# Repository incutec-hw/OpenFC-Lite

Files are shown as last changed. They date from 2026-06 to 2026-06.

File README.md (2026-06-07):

# OpenFC-Lite

Open-source Betaflight flight controller built on the RP2354B — 6-layer, 30.5×30.5 mm mounting, 3S–6S input, microSD blackbox, analog OSD.

<p>
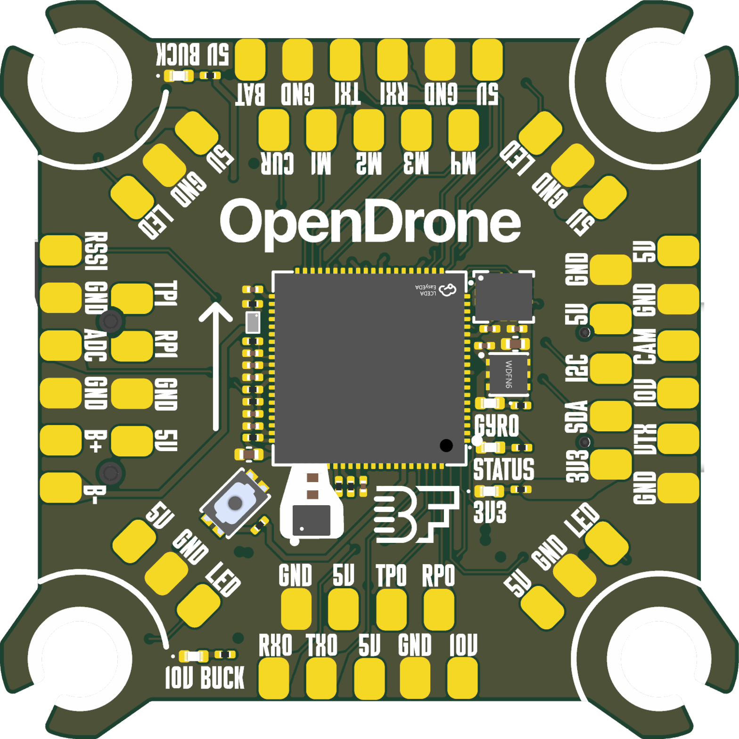
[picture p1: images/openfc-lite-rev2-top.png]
OpenFC-Lite Rev 2 Top

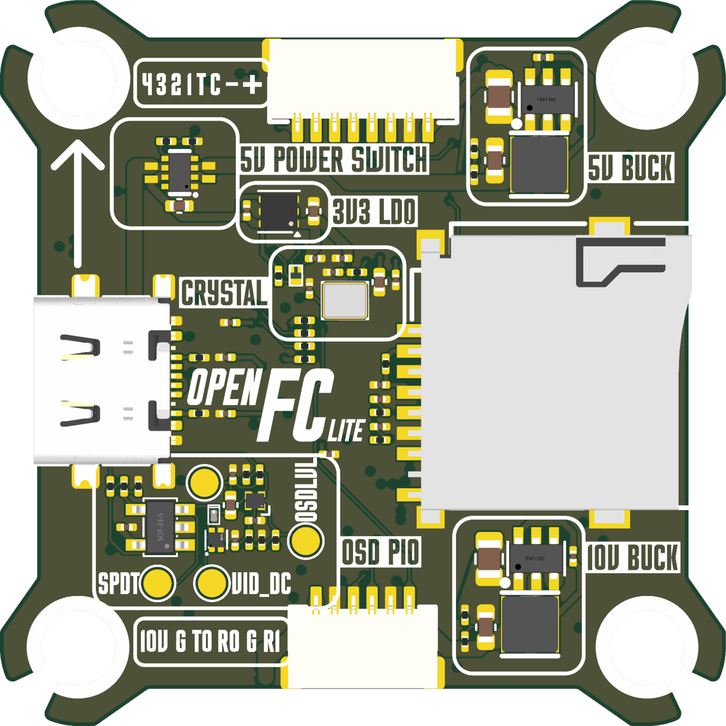
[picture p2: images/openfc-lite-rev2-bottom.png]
OpenFC-Lite Rev 2 Bottom

</p>

Motor outputs are signal-level lines that drive an external 4-in-1 ESC (e.g. OpenESC) over the 8-pin ESC connector — there are no onboard motor drivers. Barometer, integrated receiver, and onboard SPI blackbox flash are omitted by design; blackbox logging uses the microSD slot, and the receiver connects externally over UART.

> A smaller **[OpenFC-Lite-Mini](https://github.com/incutec-hw/OpenFC-Lite-Mini)** (20×20 mm, RP2354A) shares this design. **Both are being ordered for Rev 2;** this full-size board adds bigger pads, more I/O, full-size SD, and OSD debug pads.

## Specifications

| | |
|---|---|
| **MCU** | RP2354B — dual-core ARM Cortex-M33, QFN-80, integrated stacked flash (U2, LCSC C39843328) |
| **IMU** | 6-axis MEMS on SPI0, LGA-14 footprint. Rev 1 populates LSM6DSV16XTR (U9). The footprint also accepts TDK ICM-426xx/456xx — IMU is a population choice, not a layout change |
| **Barometer** | None (omitted by design) |
| **Blackbox** | microSD card slot (push-push, TF-021B-H265 family) on SPI1 |
| **OSD** | Analog, PIO-driven: sync-separator comparator + video op-amp + SPDT analog switch (no MAX7456-class OSD chip, no onboard flash). Includes OSD debug/bring-up pads (not on the Mini). |
| **Regulators** | 10V switchable buck, 5V always-on buck, USB/BATT power mux, 3.3V LDO, 1.8V gyro LDO (see power tree) |
| **UARTs** | 4 total — 2 hardware UARTs + 2 PIO software UARTs |
| **Motor outputs** | 4 (MOTOR1–MOTOR4), signal-level to external ESC |
| **Battery input** | +BATT, 3S–6S |
| **Copper layers** | 6 |
| **Board size** | 38.9 × 38.9 mm |
| **Mounting** | 30.5 × 30.5 mm pattern, 4× Ø4.0 mm holes |
| **USB** | USB-C (USB full-speed, D+/D- with 30Ω series resistors; configuration/flashing) |

### Power tree

| Rail | Source | Regulator | Notes |
|---|---|---|---|
| +10V (switchable) | +BATT | LMR51430YFDDCR buck (U3) | EN-gated via GPIO (10V_ENABLE). FB divider 100k : 6.49k → ≈9.85V. 4.7µH (L2) / 22µF 16V output. VTX/camera rail. |
| +5V (always-on) | +BATT | LMR51430YFDDCR buck (U4) | 4.7µH (L3). |
| +5V (muxed) | +5V_BUCK + +5V_USB | TPS2116DRLR (U5) | Auto-selects battery vs USB source. |
| +3.3V | +5V | LP5912-3.3DRVR (U7) | Logic LDO. |
| +1.8V_GYRO | +5V | NCV8187AMT180TAG (U6) | 1.2 A LDO, high PSRR (80 dB to 10 kHz). Dedicated IMU analog supply. |
| +1.1V | +3.3V | RP2354B internal core regulator | MCU core. |

## Connectivity / IO

**Serial**
- UART0 (UART0_TX / UART0_RX) — hardware UART
- UART1 (UART1_TX / UART1_RX) — hardware UART
- PIO UART0 (PIOUART0_TX / PIOUART0_RX) — software UART via PIO
- PIO UART1 (PIOUART1_TX / PIOUART1_RX) — software UART via PIO

**Buses**
- I2C0 (SCL / SDA) — exposed on expansion pads
- SPI0 (SCK / MOSI / MISO, + GYRO_INT) — IMU
- SPI1 (SCK / MOSI / MISO) — microSD blackbox

**Motor / actuator**
- MOTOR1, MOTOR2, MOTOR3, MOTOR4 — to external ESC
- LED_STRIP — addressable LED output
- BEEPER / BUZZER- — N-MOS-driven buzzer output

**Analog inputs (each via RC filter)**
- ADC_VBAT — battery voltage sense (resistive divider)
- ESC_CURRENT — current sense from ESC
- RSSI — analog RSSI

**OSD (analog video chain)**
- OSD_SYNC, OSD_EN, OSD_W, OSD_LVL — composite-video sync/overlay signals to the OSD front-end

**Status / control**
- LED0 — status LED
- 10V_ENABLE — switches the 10V VTX/camera rail

### Connectors

| Ref | Part | Type | Function |
|---|---|---|---|
| U8 | SM06B-SRSS-TB | 6-pin SMD JST SH | Digital VTX |
| P1 | SM08B-SRSS-TB | 8-pin TH JST SH | ESC harness |
| USB1 | Type-C 16P | USB-C | Configuration / flashing |

A large number of through-hole solder pads (J*) expose rails and signal lines (5V, GND, MOTOR1–4, UART, LED_STRIP, RSSI, etc.) for direct wiring.

## Repository structure

```
OpenFC-Lite/
├── README.md
├── LICENSE                       CERN-OHL-S-2.0
├── CLAUDE.md                     project working agreement / design notes
├── hardware/                     KiCad 9 project (single project)
│   ├── OpenFC.kicad_pro          project file
│   ├── OpenFC.kicad_sch          top-level (hierarchical) schematic
│   ├── rp2350a.kicad_sch         RP2354B MCU + support
│   ├── power.kicad_sch           regulators (10V/5V bucks, mux, 3.3V/1.8V LDOs)
│   ├── imu.kicad_sch             6-axis IMU on SPI0
│   ├── osd.kicad_sch             analog OSD chain
│   ├── blackbox.kicad_sch        microSD card slot on SPI1
│   ├── pads.kicad_sch            solder pads and connectors
│   ├── OpenFC.kicad_pcb          PCB layout (6 layers)
│   ├── OpenFC.kicad_dru          custom design rules
│   ├── lib.kicad_sym             project-local symbol library
│   ├── lib.3dshapes/             project-local 3D models
│   ├── datasheets/               component datasheets
│   ├── production/               JLCPCB exports (rev1: gerbers zip, BOM, CPL)
│   └── tools/                    read-only analysis scripts (kicad-skip / pcbnew)
├── analysis/                     netlist/IC/power extraction output
└── images/                       board renders
```

All symbol, footprint, and 3D-model libraries are project-local — no external library setup required to open the project.

## Firmware

Target firmware is **Betaflight** on the RP2350 (PICO) platform. The RP2354B uses the Raspberry Pi Pico SDK (C/C++). PIO blocks drive the DShot motor outputs, the software UARTs, the LED strip, and the analog-OSD pixel timing.

Note: the RP2350 analog-OSD (FB_OSD) driver is still an open upstream Betaflight PR stack — OSD is not yet flyable from an upstream binary. See the [Wiki](https://github.com/incutec-hw/OpenFC-Lite/wiki) for bring-up status.

## License

Hardware licensed under [CERN-OHL-S-2.0](https://ohwr.org/cern_ohl_s_v2.txt). See [LICENSE](LICENSE).

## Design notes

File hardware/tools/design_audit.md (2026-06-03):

# OpenFC-Lite Design Audit

Generated from `OpenFC.kicad_sch` + `OpenFC.kicad_pcb` via kicad-skip + pcbnew.

## 1. Top-level Hierarchy

| Sheetname | File | On disk |
|---|---|---|
| BLACKBOX | `blackbox.kicad_sch` | yes |
| IMU | `imu.kicad_sch` | yes |
| OSD | `osd.kicad_sch` | yes |
| RP2350A | `rp2350a.kicad_sch` | yes |
| PADS | `pads.kicad_sch` | yes |
| POWER | `power.kicad_sch` | yes |

Root schematic: `OpenFC.kicad_sch` — 6 sub-sheet(s) referenced.

## 2. Component Inventory

Total placed refs: **168** (DNP excluded: 1).

### MCU (1)

| Ref | Value | MPN | LCSC | Mfr | Footprint | Sheet |
|---|---|---|---|---|---|---|
| U36 | RP2354B_C39843328 | RP2354B | C39843328 | Raspberry Pi | QFN-80_L10.0-W10.0-P0.40-TL-EP3.4 | rp2350a |

### IMU (1)

| Ref | Value | MPN | LCSC | Mfr | Footprint | Sheet |
|---|---|---|---|---|---|---|
| U14 | LSM6DSV16XTR | LSM6DSV16XTR | C5267406 | STMicroelectronics | LGA-14_L3.0-W2.5-P0.50-BR | imu |

### Buck (2)

| Ref | Value | MPN | LCSC | Mfr | Footprint | Sheet |
|---|---|---|---|---|---|---|
| U6 | LMR51420YFDDCR | LMR51420YFDDCR | C7296200 | Texas Instruments | SOT-23-6_L2.9-W1.6-P0.95-LS2.9-BL | power |
| U7 | LMR51420YFDDCR | LMR51420YFDDCR | C7296200 | Texas Instruments | SOT-23-6_L2.9-W1.6-P0.95-LS2.9-BL | power |

### LDO (2)

| Ref | Value | MPN | LCSC | Mfr | Footprint | Sheet |
|---|---|---|---|---|---|---|
| U13 | LP5912-3.3DRVR | LP5912-3.3DRVR | C524780 | Texas Instruments | WSON-6-1EP_2x2mm_P0.65mm_EP1x1.6mm | power |
| U21 | NCV8187AMT180TAG | NCV8187AMT180TAG | C893189 | onsemi | WDFN-6_L2.0-W2.0-P0.65-BL-EP | power |

### Power Mux (1)

| Ref | Value | MPN | LCSC | Mfr | Footprint | Sheet |
|---|---|---|---|---|---|---|
| U33 | TPS2116DRLR | TPS2116DRLR | C3235557 | Texas Instruments | SOT-583-8_L2.1-W1.6-P0.50-LS1.6-BL | power |

### OSD (3)

| Ref | Value | MPN | LCSC | Mfr | Footprint | Sheet |
|---|---|---|---|---|---|---|
| U34 | TLV3201AIDBVR | TLV3201AIDBVR | C105188 | Texas Instruments | SOT-23-5_L3.0-W1.7-P0.95-LS2.8-BR | osd |
| U35 | SN74LVC1G3157DTBR | SN74LVC1G3157DTBR | C2673087 | Texas Instruments | X2SON-6_L1.0-W0.8-BL | osd |
| U38 | TLV9061IDPWR | TLV9061IDPWR | C2057878 | Texas Instruments | X2SON-4_L0.8-W0.8-P0.48-TL-DPW | osd |

### SD card (1)

| Ref | Value | MPN | LCSC | Mfr | Footprint | Sheet |
|---|---|---|---|---|---|---|
| Card2 | TF-021B-H265 | TF-021B-H265 | C498185 | - | TF-SMD_TF-021B-H265 | blackbox |

### USB (1)

| Ref | Value | MPN | LCSC | Mfr | Footprint | Sheet |
|---|---|---|---|---|---|---|
| USB1 | TYPE-C 16P QTWT | TYPE-C 16P QTWT | C5187472 | SHOU HAN | USB-TYPE-C-SMD_TYPE-C-16P-QTWT | rp2350a |

### Switch (1)

| Ref | Value | MPN | LCSC | Mfr | Footprint | Sheet |
|---|---|---|---|---|---|---|
| U32 | TS2306A 240GF MSM 9_C2976675 | TS2306A 240gf MSM 9 | C2976675 | SHOU HAN | SW-SMD_4P-L3.0-W2.0-P0.85-LS3.5 | rp2350a |

### MOSFET (4)

| Ref | Value | MPN | LCSC | Mfr | Footprint | Sheet |
|---|---|---|---|---|---|---|
| Q1 | DMN1150UFB-7B | DMN1150UFB-7B | C459538 | Diodes Incorporated | DFN-3L_L1.0-W0.6-P0.65-BR | power |
| Q2 | DMN1150UFB-7B | DMN1150UFB-7B | C459538 | Diodes Incorporated | DFN-3L_L1.0-W0.6-P0.65-BR | rp2350a |
| Q3 | DMN1150UFB-7B | DMN1150UFB-7B | C459538 | Diodes Incorporated | DFN-3L_L1.0-W0.6-P0.65-BR | rp2350a |
| Q7 | DMN1150UFB-7B | DMN1150UFB-7B | C459538 | Diodes Incorporated | DFN-3L_L1.0-W0.6-P0.65-BR | rp2350a |

### Diode/LED (5)

| Ref | Value | MPN | LCSC | Mfr | Footprint | Sheet |
|---|---|---|---|---|---|---|
| D1 | LED_1_Green | XL-0201UGC | C3646922 | XINGLIGHT | LED_0201_0603Metric | power |
| D2 | LED_1_Green | XL-0201UGC | C3646922 | XINGLIGHT | LED_0201_0603Metric | rp2350a |
| D4 | LED_1_Green | XL-0201UGC | C3646922 | XINGLIGHT | LED_0201_0603Metric | power |
| D5 | LED_1_Green | XL-0201UGC | C3646922 | XINGLIGHT | LED_0201_0603Metric | power |
| D7 | LED_1_Green | XL-0201UGC | C3646922 | XINGLIGHT | LED_0201_0603Metric | power |

### Diode (4)

| Ref | Value | MPN | LCSC | Mfr | Footprint | Sheet |
|---|---|---|---|---|---|---|
| D3 | RB161QS-40_C28646385 | RB161QS-40 | C28646385 | ROHM | SOD-882_L1.0-W0.6-RD | power |
| D8 | USBLC6-2P6 | USBLC6-2P6 | C15999 | STMicroelectronics | SOT-666 | rp2350a |
| D9 | SDM02U30LP3-7B | SDM02U30LP3-7B | C151629 | Diodes Incorporated | X3-DFN0603-2_L0.6-W0.3-RD | osd |
| D21 | RB161QS-40_C28646385 | RB161QS-40 | C28646385 | ROHM | SOD-882_L1.0-W0.6-RD | power |

### IC (1)

| Ref | Value | MPN | LCSC | Mfr | Footprint | Sheet |
|---|---|---|---|---|---|---|
| U1 | SM06B-SRSS-TB(LF)(SN) | SM06B-SRSS-TB(LF)(SN) | C160405 | JST | CONN-SMD_SM06B-SRSS-TB-LF-SN | pads |

### Inductor (3)

| Ref | Value | MPN | LCSC | Mfr | Footprint | Sheet |
|---|---|---|---|---|---|---|
| L1 | AOTA-B201610S3R3-101-T | AOTA-B201610S3R3-101-T | C42411119 | Abracon | IND-SMD_L2.0-W1.6_AOTA-B201610S3R3-101-T | rp2350a |
| L3 | XRTC303020D4R7MBCA | XRTC303020D4R7MBCA | C39846837 | XR | IND-SMD_L3.0-W3.0_AFE303020S | power |
| L4 | XRTC303020D4R7MBCA | XRTC303020D4R7MBCA | C39846837 | XR | IND-SMD_L3.0-W3.0_AFE303020S | power |

### Connector / Solder Pads (54)

(full net list in section 14)

| Footprint | Sheet | Count |
|---|---|---|
| small_pad | pads | 54 |

### Passives summary

| Function | Placed | DNP |
|---|---|---|
| Resistor | 44 | 0 |
| Capacitor | 38 | 0 |
| Test Pad | 0 | 0 |

## 3. Power Tree

```
+BATT -> U6 (LMR51420YFDDCR buck) -> +12V   [switchable via GPIO11 via Q?]
+BATT -> U7 (LMR51420YFDDCR buck) -> +5V_BUCK
+5V_BUCK -+
          +- U33 (TPS2116 mux) -> +5V
VBUS(USB)-+
+5V -> U13 (LP5912-3.3) -> +3.3V
+3.3V -> U36 (RP2354B VREG) -> +1.1V_CORE (DVDD)
+5V -> U21 (NCV8187 LDO) -> +1.8V_GYRO
```

| Ref | Role | MPN | Footprint | Pad → Net |
|---|---|---|---|---|
| U6 | 12V buck | LMR51420YFDDCR | SOT-23-6_L2.9-W1.6-P0.95-LS2.9-BL | 1→GND; 2→Net-(U6-SW); 3→+BATT; 4→Net-(U6-FB); 5→/POWER/10V_ENABLE; 6→Net-(U6-CB) |
| U7 | 5V buck | LMR51420YFDDCR | SOT-23-6_L2.9-W1.6-P0.95-LS2.9-BL | 1→GND; 2→Net-(U7-SW); 3→+BATT; 4→Net-(U7-FB); 5→+BATT; 6→Net-(U7-CB) |
| U13 | 3.3V LDO | LP5912-3.3DRVR | WSON-6-1EP_2x2mm_P0.65mm_EP1x1.6mm | 1→+3.3V; 2→unconnected-(U13-NC-Pad2); 3→GND; 4→+5V; 5→GND; 6→+5V; 7→GND; → |
| U21 | 1.8V gyro LDO | NCV8187AMT180TAG | WDFN-6_L2.0-W2.0-P0.65-BL-EP | 1→+5V; 2→+5V; 3→GND; 4→/POWER/1.8V_PG; 5→+1.8V_GYRO; 6→+1.8V_GYRO |
| U33 | 5V power mux | TPS2116DRLR | SOT-583-8_L2.1-W1.6-P0.50-LS1.6-BL | 1→GND; 2→+5V; 3→+5V_BUCK; 4→Net-(U33-PR1); 5→+5V_BUCK; 6→+5V_USB; 7→+5V; 8→unconnected-(U33-ST-Pad8) |

## 4. Bypass caps per power rail

| Rail | Net | # Caps to GND | Cap refs |
|---|---|---|---|
| +BATT | +BATT | 2 | C35, C37 |
| +12V | — (net not found) | - | - |
| +5V_BUCK | +5V_BUCK | 1 | C40 |
| +5V | +5V | 3 | C32, C33, C48 |
| VBUS | — (net not found) | - | - |
| +3.3V | +3.3V | 17 | C1, Card2, C3, C16, C30, C31, C34, C42, C43, C44, C49, C50, C51, C52, C65, C67, C69 |
| +1.8V_GYRO | +1.8V_GYRO | 2 | C2, C41 |
| +1.1V | +1.1V | 4 | C27, C28, C29, C68 |
| +1.1V_CORE | — (net not found) | - | - |
| DVDD | — (net not found) | - | - |

Rail-like nets present:

`+10V`, `+5V`, `+5V_BUCK`, `+5V_USB`, `/POWER/10V_ENABLE`

## 5. ADC Inputs

| Role | Net | MCU pad | Resistors on net | Bypass caps to GND |
|---|---|---|---|---|
| VBAT_SENSE | /RP2350A/ADC_VBAT | 52 | R35, R43 | C56 |
| CURR_SENSE | /PADS/CURRENT | 49 | — | **NONE** |
| RSSI | /PADS/RSSI | 56 | — | **NONE** |
| EXT | — not found | - | - | - |

**Check**: A CURRENT-sense ADC input WITHOUT a bypass cap at the MCU pin is a Betaflight MFG-guideline violation (noise couples straight into ADC).

## 6. SPI Buses & CS pull-ups

| Signal | Net | Refs on net | Resistors (pull-ups?) |
|---|---|---|---|
| SPI0 SCK | — | - | - |
| SPI0 MOSI | — | - | - |
| SPI0 MISO | — | - | - |
| IMU CS | /IMU/GYRO_CS | U14, U36 | — |
| SD CS | /BLACKBOX/BB_CS | Card2, R2, U36 | R2 |
| SD MOSI | — | - | - |
| SD MISO | — | - | - |
| SD SCK | — | - | - |

### CS pull-up check (to +3.3V)

| CS line | Net | Pull-up present? | Pull-up ref |
|---|---|---|---|
| IMU_CS (U14 pad 12) | /IMU/GYRO_CS | NO | - |
| SD_CS (Card2 pad 2) | /BLACKBOX/BB_CS | YES | R2 |

## 7. Status LEDs (non-WS2812)

| Ref | Value/Color | MPN | Pad nets | Likely MCU-side net |
|---|---|---|---|---|
| D1 | LED_1_Green | XL-0201UGC | →, 1→GND, 2→Net-(D1-A) | , Net-(D1-A) |
| D2 | LED_1_Green | XL-0201UGC | →, 1→GND, 2→Net-(D2-A) | , Net-(D2-A) |
| D4 | LED_1_Green | XL-0201UGC | →, 1→GND, 2→Net-(D4-A) | , Net-(D4-A) |
| D5 | LED_1_Green | XL-0201UGC | →, 1→GND, 2→Net-(D5-A) | , Net-(D5-A) |
| D7 | LED_1_Green | XL-0201UGC | →, 1→Net-(D7-K), 2→Net-(D7-A) | , Net-(D7-K), Net-(D7-A) |

Blue LED (Betaflight LED0 requirement): **MISSING** (none)

## 8. I2C Pull-ups

| Signal | Net | Refs on net | Pull-up to 3.3V |
|---|---|---|---|
| I2C_SDA | /I2C_SDA | J7, R42, U36 | YES |
| I2C_SCL | /I2C_SCL | J8, R41, U36 | YES |

## 9. RP2354B (U36) Pinout

| Pad | Net |
|---|---|
| 3 | /RP2350A/BEEPER |
| 5 | +3.3V |
| 7 | /RP2350A/SBUS_INVERT |
| 9 | /POWER/10V_ENABLE |
| 10 | +1.1V |
| 11 | /RP2350A/LED0 |
| 12 | /IMU/GYRO_INT |
| 13 | /IMU/GYRO_CS |
| 14 | /IMU/SPI0.CLKIN |
| 15 | +3.3V |
| 16 | /I2C_SDA |
| 17 | /I2C_SCL |
| 18 | /IMU/SPI0.SCK |
| 19 | /IMU/SPI0.MOSI |
| 20 | /IMU/SPI0.MISO |
| 21 | /UART1_RX |
| 22 | /UART1_TX |
| 23 | /RP2350A/LED_STRIP_L |
| 24 | +3.3V |
| 25 | /RP2350A/ESP_EN |
| 26 | /RP2350A/ESP_BOOT |
| 27 | /PADS/PIOUART1_TX |
| 28 | /PADS/PIOUART1_RX |
| 29 | +3.3V |
| 30 | /RP2350A/XIN |
| 31 | /RP2350A/XOUT |
| 32 | +1.1V |
| 35 | Net-(U36-RUN) |
| 36 | /PADS/M4 |
| 37 | /PADS/M3 |
| 38 | /PADS/M2 |
| 39 | /PADS/M1 |
| 41 | +3.3V |
| 42 | /OSD/OSD_W |
| 43 | /OSD/OSD_EN |
| 44 | /OSD/OSD_SYNC |
| 49 | /PADS/CURRENT |
| 50 | +3.3V |
| 51 | +1.1V |
| 52 | /RP2350A/ADC_VBAT |
| 53 | /BLACKBOX/SPI1.SCK |
| 54 | /BLACKBOX/SPI1.MOSI |
| 55 | /BLACKBOX/SPI1.MISO |
| 56 | /PADS/RSSI |
| 57 | /BLACKBOX/BB_CS |
| 58 | /PADS/ADC2 |
| 59 | Net-(U36-ADC_AVDD) |
| 60 | +3.3V |
| 61 | Net-(U36-VREG_AVDD) |
| 62 | GND |
| 63 | Net-(U36-VREG_LX) |
| 64 | +3.3V |
| 65 | +1.1V |
| 66 | Net-(U36-USB_DM) |
| 67 | Net-(U36-USB_DP) |
| 68 | +3.3V |
| 69 | +3.3V |
| 75 | Net-(U36-QSPI_SS) |
| 76 | +3.3V |
| 77 | /PADS/DIGITAL_TX |
| 78 | /PADS/DIGITAL_RX |
| 79 | /PADS/PIOUART0_TX |
| 80 | /PADS/PIOUART0_RX |
| 81 | GND |

## 10. OSD Circuit

| Ref | Value | Footprint | Pad → Net |
|---|---|---|---|
| U34 | TLV3201AIDBVR | SOT-23-5_L3.0-W1.7-P0.95-LS2.8-BR | 1→/OSD/OSD_SYNC; 2→GND; 3→/OSD/VID_DC; 4→GND; 5→+3.3V |
| U38 | TLV9061IDPWR | X2SON-4_L0.8-W0.8-P0.48-TL-DPW | 1→Net-(U38-OUT); 2→Net-(U38-IN-); 3→GND; 4→Net-(U35-A); 5→+3.3V |
| U35 | SN74LVC1G3157DTBR | X2SON-6_L1.0-W0.8-BL | 1→/OSD/OSD_LVL; 2→GND; 3→/OSD/VIDEO_IN; 4→Net-(U35-A); 5→+3.3V; 6→/OSD/OSD_EN |

## 11. SD Card (Blackbox)

| Ref | Value | Footprint | Pad → Net |
|---|---|---|---|
| Card2 | TF-021B-H265 | TF-SMD_TF-021B-H265 | 1→Net-(Card2-DAT2); 2→/BLACKBOX/BB_CS; 3→/BLACKBOX/SPI1.MOSI; 4→+3.3V; 5→/BLACKBOX/SPI1.SCK; 6→GND; 7→/BLACKBOX/SPI1.MISO; 8→Net-(Card2-DAT1); 9→GND; 10→GND |

## 12. Motor Outputs (M1-M4)

| Motor net | Refs on net |
|---|---|
| /PADS/M1 | J4, P1, U36 |
| /PADS/M2 | J3, P1, U36 |
| /PADS/M3 | J2, P1, U36 |
| /PADS/M4 | J1, P1, U36 |

## 13. Reset / Boot

- **RUN**: net `Net-(U36-RUN)` — refs: R36, U36
- U36 pad 35 (RUN) connects to `Net-(U36-RUN)`; refs on net: R36, U36

## 14. Connectors & Pads

### Solder Pads / Connectors

| Ref | Footprint | Pad → Net |
|---|---|---|
| J1 | small_pad | /PADS/M4 |
| J2 | small_pad | /PADS/M3 |
| J3 | small_pad | /PADS/M2 |
| J4 | small_pad | /PADS/M1 |
| J5 | small_pad | GND |
| J6 | small_pad | +5V |
| J7 | small_pad | /I2C_SDA |
| J8 | small_pad | /I2C_SCL |
| J9 | small_pad | GND |
| J13 | small_pad | +5V |
| J14 | small_pad | GND |
| J15 | small_pad | /LED |
| J16 | small_pad | +5V |
| J17 | small_pad | GND |
| J18 | small_pad | /LED |
| J19 | small_pad | +5V |
| J20 | small_pad | GND |
| J21 | small_pad | /LED |
| J22 | small_pad | +5V |
| J23 | small_pad | GND |
| J24 | small_pad | /PADS/CURRENT |
| J25 | small_pad | GND |
| J27 | small_pad | +BATT |
| J28 | small_pad | +10V |
| J29 | small_pad | GND |
| J30 | small_pad | /LED |
| J32 | small_pad | /OSD/VIDEO_IN |
| J33 | small_pad | /OSD/VIDEO_OUT |
| J34 | small_pad | +5V |
| J35 | small_pad | /PADS/DIGITAL_TX |
| J36 | small_pad | /PADS/DIGITAL_RX |
| J37 | - |  |
| J38 | small_pad | /PADS/SBUS |
| J39 | small_pad | +5V |
| J40 | small_pad | /PADS/BUZZER- |
| J41 | small_pad | GND |
| J42 | small_pad | GND |
| J43 | small_pad | /UART1_TX |
| J44 | small_pad | /UART1_RX |
| J45 | small_pad | /PADS/PIOUART0_RX |
| J46 | small_pad | /PADS/PIOUART0_TX |
| J47 | small_pad | GND |
| J48 | small_pad | +5V |
| J49 | small_pad | +5V |
| J50 | small_pad | GND |
| J51 | small_pad | GND |
| J52 | small_pad | /PADS/ADC2 |
| J53 | small_pad | +5V |
| J54 | small_pad | GND |
| J55 | small_pad | /PADS/PIOUART1_TX |
| J56 | small_pad | /PADS/RSSI |
| J57 | small_pad | /PADS/PIOUART1_RX |
| J58 | small_pad | +10V |
| J59 | small_pad | +3.3V |

### USB

| Ref | Footprint | Pad → Net |
|---|---|---|
| USB1 | USB-TYPE-C-SMD_TYPE-C-16P-QTWT | p0→GND; p→; pA1→GND; pA4→+5V_USB; pA5→Net-(USB1-CC1); pA6→/RP2350A/D+_C; pA7→/RP2350A/D-_C; pA9→+5V_USB; pA12→GND; pB5→Net-(USB1-CC2); pB6→/RP2350A/D+_C; pB7→/RP2350A/D-_C |

## 15. CLAUDE.md GPIO map cross-check

| GPIO | CLAUDE.md function | U36 pad | Net |
|---|---|---|---|
| GPIO0 | UART0 TX | 77 | /PADS/DIGITAL_TX |
| GPIO1 | UART0 RX | 78 | /PADS/DIGITAL_RX |
| GPIO2 | PIO UART0 TX | 79 | /PADS/PIOUART0_TX |
| GPIO3 | PIO UART0 RX | 80 | /PADS/PIOUART0_RX |
| GPIO6 | Beeper | 3 | /RP2350A/BEEPER |
| GPIO11 | 10V enable | 9 | /POWER/10V_ENABLE |
| GPIO12 | Status LED | 11 | /RP2350A/LED0 |
| GPIO13 | IMU INT | 12 | /IMU/GYRO_INT |
| GPIO14 | IMU CS | 13 | /IMU/GYRO_CS |
| GPIO18 | IMU SCK | 18 | /IMU/SPI0.SCK |
| GPIO19 | IMU MISO | 19 | /IMU/SPI0.MOSI |
| GPIO20 | IMU MOSI | 20 | /IMU/SPI0.MISO |
| GPIO21 | UART1 RX | 21 | /UART1_RX |
| GPIO22 | UART1 TX | 22 | /UART1_TX |
| GPIO23 | LED strip | 23 | /RP2350A/LED_STRIP_L |
| GPIO26 | PIO UART1 TX | 27 | /PADS/PIOUART1_TX |
| GPIO27 | PIO UART1 RX | 28 | /PADS/PIOUART1_RX |
| GPIO28 | M4 | 36 | /PADS/M4 |
| GPIO29 | M3 | 37 | /PADS/M3 |
| GPIO30 | M2 | 38 | /PADS/M2 |
| GPIO31 | M1 | 39 | /PADS/M1 |
| GPIO32 | OSD VBLACK | — | — (GPIO not wired on MCU) |
| GPIO33 | OSD SYNC_IN | 42 | /OSD/OSD_W |
| GPIO34 | OSD PIXEL_SEL | 43 | /OSD/OSD_EN |
| GPIO35 | OSD VWHITE | 44 | /OSD/OSD_SYNC |
| GPIO36 | OSD COLOR_SEL | — | — (GPIO not wired on MCU) |
| GPIO37 | OSD SYNCLVL | — | — (GPIO not wired on MCU) |
| GPIO40 | CURRENT ADC | 49 | /PADS/CURRENT |
| GPIO41 | VBAT ADC | 52 | /RP2350A/ADC_VBAT |
| GPIO45 | RSSI ADC | 56 | /PADS/RSSI |
| GPIO47 | EXT ADC | 58 | /PADS/ADC2 |

GPIOs wired on MCU but not documented in CLAUDE.md:

| GPIO | U36 pad | Net |
|---|---|---|
| GPIO9 | 7 | /RP2350A/SBUS_INVERT |
| GPIO15 | 14 | /IMU/SPI0.CLKIN |
| GPIO16 | 16 | /I2C_SDA |
| GPIO17 | 17 | /I2C_SCL |
| GPIO24 | 25 | /RP2350A/ESP_EN |
| GPIO25 | 26 | /RP2350A/ESP_BOOT |
| GPIO42 | 53 | /BLACKBOX/SPI1.SCK |
| GPIO43 | 54 | /BLACKBOX/SPI1.MOSI |
| GPIO44 | 55 | /BLACKBOX/SPI1.MISO |
| GPIO46 | 57 | /BLACKBOX/BB_CS |

## 16. Audit findings

| Severity | Finding |
|---|---|
| HIGH | CURRENT-sense net `/PADS/CURRENT` has NO bypass cap to GND — add ~100nF near MCU ADC pin. |
| LOW | RSSI ADC net `/PADS/RSSI` has no bypass cap to GND (acceptable for PWM/analog RSSI). |
| HIGH | IMU CS net `/IMU/GYRO_CS` (U14 pad 12) has NO pull-up to 3.3V — floating CS at boot can cause bus contention; add 10k to +3.3V. |
| MED | No explicit BLUE LED found for Betaflight LED0 status. |

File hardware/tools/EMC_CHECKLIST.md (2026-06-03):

# OpenFC-Lite EMC Checklist

## Noise sources (ranked by threat)

| Source | Frequency | Notes |
|---|---|---|
| LMR51420/30 bucks U3, U4 | 1.1 MHz fundamental + harmonics to ~200 MHz | Strongest radiator |
| RP2350 internal core buck | ~400 kHz variable | Hard to isolate, close to MCU |
| 12 MHz crystal X1 | 12 MHz + harmonics | Can alias into RX bands |
| DShot600 motor outputs | 600 kHz, 12-20 ns edges | Broadband from fast edges |
| SPI0 IMU clock | up to 10 MHz | Low level, well shielded |
| SPI1 SD card | up to 25 MHz | Bursty, noisy |
| USB D+/D- | 12 Mbps FS | Contained if routed right |

## 1. Buck switch node loops (L2, L3)

- CIN GND + COUT GND on local top-side island, NOT merged into main GND pour
- 2 adjacent stitching vias per buck to inner GND plane
- SW node: just wide enough for current (~0.5 mm), short (<5 mm), minimum area
- No GND pour directly under SW trace on top AND on layer 2
- No GND pour directly under inductor body
- L2 and L3 >5 mm apart (avoid mutual coupling)
- FB trace away from SW node, under a GND shield layer

## 2. IMU (U9 LSM6DSV16X) immunity

- Place >=10 mm from any switch node (L1, L2, L3)
- Over solid inner GND plane, no splits underneath
- 1.8V_GYRO rail: continuous GND return, no crossings
- NCV8187 LDO output within 5 mm of IMU VDD pin
- IMU CS/SCK/MOSI/MISO tightly grouped with GND ref, NOT over SW nodes
- 100 nF VDD + 100 nF VDDIO within 1 mm of pins
- SPI1 (SD card) not parallel to SPI0 (IMU) with <0.5 mm spacing

## 3. ADC inputs (VBAT, CURRENT, RSSI, EXT)

- RC filters (1k + 100nF) within 5 mm of MCU ADC pins (already in schematic)
- ADC traces short, routed over GND plane
- VBAT divider resistors away from buck switch nodes
- No long traces parallel to digital clocks

## 4. USB D+/D-

- 27 ohm series R immediately next to MCU pins 66/67
- 90 ohm differential impedance target
- Continuous GND plane beneath full length, no splits
- GND stitching vias flanking any layer transition
- USBLC6 ESD AT connector (not near MCU)
- CC1/CC2 5.1 kOhm pull-downs present and correct

## 5. Motor outputs M1-M4

- On board edge (already - P1)
- 22-33 ohm series R in-line at MCU (currently 0 ohm)
- Route over GND plane, distance from IMU
- DShot edges radiate

## 6. Crystal X1 (12 MHz)

- Crystal + 2 load caps directly under XIN/XOUT pins, <3 mm stubs
- GND guard ring tied to inner plane via 2+ vias
- No ground flood BETWEEN XIN/XOUT traces
- Load caps same side as crystal
- No high-speed signals within 5 mm

## 7. Power rail filtering / bulk caps

- Bulk 47-100 uF low-ESR electrolytic at BATT input (ceramics alone insufficient)
- +5V and +10V outputs: ferrite bead + bulk cap at each connector (VTX, RX)
- Common-mode choke or ferrite bead on VTX 10V line helps conducted EMI
- Large ground copper area around each regulator

## 8. Connector ESD / surge

- TVS 5V uni-directional on every external I/O pad:
  - RX UART, SBUS, LED strip, Buzzer, Current sense, RSSI, Cam video
- Currently only USB has ESD (USBLC6) - ADD protection to others
- Series R (100-470 ohm) on LED strip + ESD diode
- Series R on beeper drive

## 9. GND plane topology (6-layer)

- Solid continuous GND plane on layer 2 under top signals, no splits
- No separate analog/digital GND islands
- Star point: all power-entry GNDs meet at same pour region
- GND stitching vias every 5-10 mm
- No splits under IMU, ADC pins, or crystal

## 10. RX / VTX rail considerations

- No onboard RF on ECO (ELRS removed)
- LED_STRIP output kept away from UART lines (WS2812 bursts noisy)
- 10V VTX rail traces >=20 mil wide, inner plane or heavy top/bottom copper
- Bulk 22-47 uF electrolytic at VTX connector for load transients
- Optional: ferrite bead in series before bulk cap

## 11. Signal integrity

- DShot600 PIO outputs: if trace >30 mm, add 22-33 ohm series termination
- SPI1 (SD card) at 25 MHz: <50 mm bus, same layer, continuous GND ref
- LED_STRIP 1 MHz bursts: 22 ohm series at MCU output

## 12. Shielding / enclosure

- Mounting hole via stitches for frame-as-shield (optional)
- Conformal coating over buck area (usually not needed for FPV)

## Priority

**Must-fix before fab:**
1. Buck hot-loop GND islands + separate stitching vias (U3, U4)
2. SW node area minimization + copper cutaway beneath
3. IMU physical distance from L1/L2/L3 (>=10 mm)
4. USB ESD placed AT connector, GND continuity under diff pair
5. Crystal guard ring + direct placement under XIN/XOUT

**Strongly recommended:**
6. 22-33 ohm series on motor lines + LED strip
7. ESD diodes on RX UART, Current, RSSI, Video pads
8. Bulk electrolytic at battery input and VTX connector
9. Ferrite bead + bulk on 5V/10V outputs to connectors

**Nice to have:**
10. Common-mode choke on USB D+/D-
11. Conformal coating zone around bucks

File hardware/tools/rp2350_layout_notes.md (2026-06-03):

# RP2350B Two-Sided Layout Rules

Source: RP2350 Datasheet §6.3.8.1, Hardware Design with RP2350 guide (Raspberry Pi).

## Hard constraint — buck regulator must stay on MCU side

Direct quote from RP2350 Datasheet §6.3.8.1:

> "Don't place any of C_IN / L_X / C_OUT on the opposite side of the PCB."
> "Follow this layout as closely as possibly."

This means the following MUST stay on the top side with the MCU:

| Ref | Part | Role |
|---|---|---|
| C_IN (4.7µF) | Buck input cap | part of high-current hot loop |
| L_X (L1, 3.3µH, Abracon AOTA-B201610S3R3-101-T, 0806) | Buck inductor | switch-node path |
| C_OUT (4.7µF) | Buck output cap | part of hot loop |
| R3 (33Ω) + C9 (4.7µF) | VREG_AVDD filter | needs own GND via back to QFN pad |
| DVDD 100nF × 2 (nearest regulator) | Core decoupling | part of COUT hot loop |

Footprint zone: ~6×4 mm cluster near pins 60-65.

Additional rules for this zone:
- Cut away copper immediately under L_X / VREG_LX switch node trace on top layer AND inner layer 2 (6-layer boards)
- GND vias back to QFN center pad: use **2 adjacent vias** to reduce impedance, "short-as-possible"
- CFILT GND path MUST NOT share vias with C_IN/C_OUT high-current GND
- VREG_FB: feed from COUT output, do NOT route under LX

## Can go on bottom side

| Component | Rule |
|---|---|
| DVDD 100nF × 4-5 (far from regulator, opposite edge of QFN) | 2 GND vias per cap |
| 2nd 4.7µF on V_OUT (C10, opposite edge) | Explicitly recommended by RPi to be AWAY from regulator |
| IOVDD 100nF caps (all 8) | 2 GND vias per cap, directly under pin |
| QSPI_IOVDD 100nF (pin 69) | same |
| USB_OTP_VDD 100nF (pin 5) | same |
| ADC_AVDD 100nF (pin 60 area) | same |
| Crystal (12 MHz) + load caps | Risky but doable — see crystal notes |
| USB ESD diode + Type-C connector | OK after R7/R8 |

## Crystal on bottom — caveats

- RP2350 uses 10.5 pF total load, ~3 pF parasitic budget
- Each via adds 0.3-0.5 pF → 2 vias = ~1 pF budget consumed
- Place crystal directly under XIN/XOUT pins (pins 30/31), minimize stubs
- Both load caps on same side as crystal
- May need to retune R2 (1kΩ damping) or load caps (try 12pF instead of 15pF)
- No ground flood between XIN/XOUT; maintain GND reference plane

## USB — near-MCU placement

- R7/R8 (27Ω series termination): stay on **top side** immediately adjacent to pins 66/67
- Differential pair can transition to bottom via vias AFTER the series resistors
- Add flanking GND vias at layer transition for return-path continuity
- Solid uninterrupted GND beneath D+/D- the entire length

## Summary strategy for OpenFC-Lite

Top side (MCU-only vision not achievable — keeps these):
- RP2354B MCU
- Buck cluster: C_IN, L1, C_OUT, R3, C9 (~5 small parts, ~6×4 mm)
- 2 DVDD 100nF caps closest to regulator
- USB R7/R8 27Ω series resistors

Bottom side:
- 4-5 remaining DVDD 100nF caps + 4.7µF C10 on opposite QFN edge
- All IOVDD / QSPI_IOVDD / USB_OTP_VDD / ADC_AVDD 100nF caps
- Crystal + load caps (directly under pins 30/31)
- USB ESD diode + USB-C connector
- All other support circuits (LDOs, power mux, IMU, OSD, SD card, connectors etc.)

## Sources

- RP2350 Datasheet: https://datasheets.raspberrypi.com/rp2350/rp2350-datasheet.pdf
- Hardware Design with RP2350: https://datasheets.raspberrypi.com/rp2350/hardware-design-with-rp2350.pdf
- Reference RP2350B FC designs: madflight FC3v2, TichyTech rp2350-flight-controller

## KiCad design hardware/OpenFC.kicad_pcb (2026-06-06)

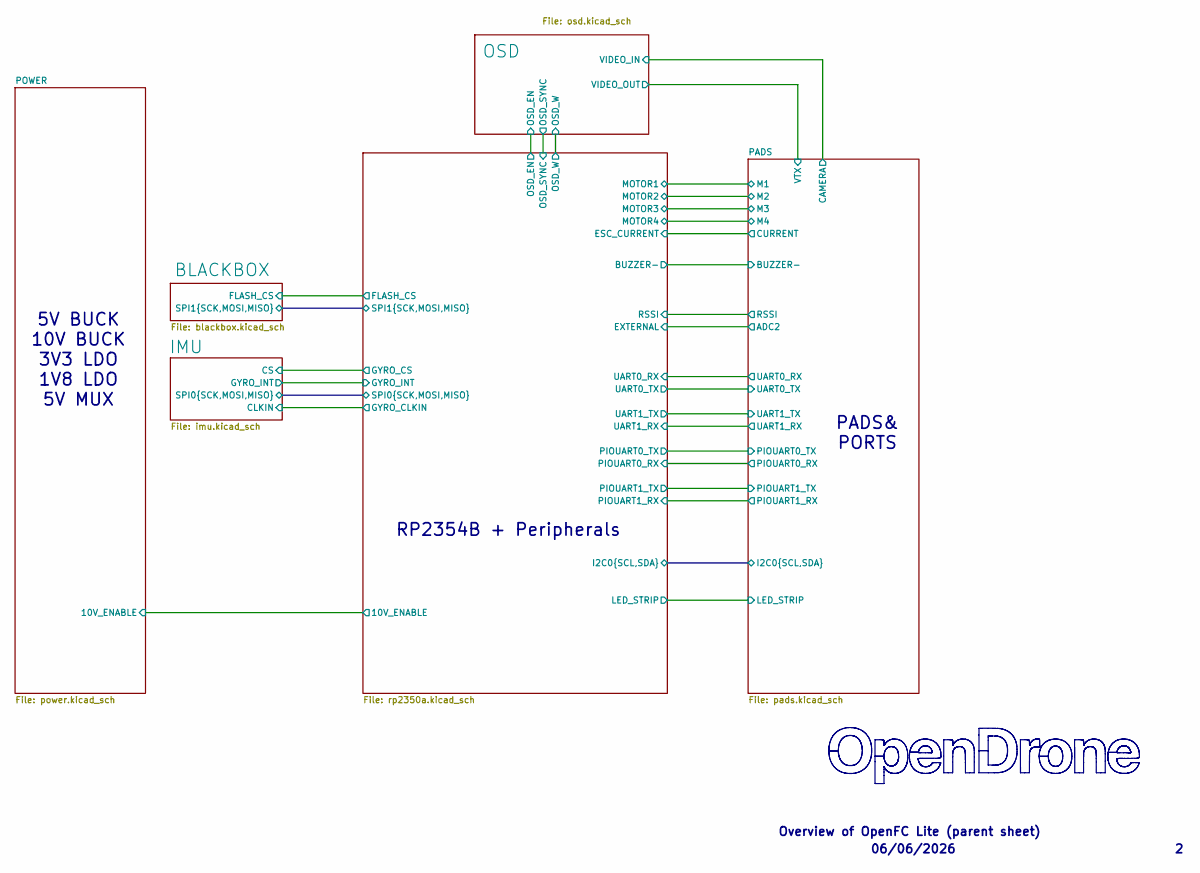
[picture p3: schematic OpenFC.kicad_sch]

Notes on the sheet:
Overview of OpenFC Lite (parent sheet)
5V BUCK 10V BUCK 3V3 LDO 1V8 LDO 5V MUX
06/06/2026
RP2354B + Peripherals
PADS& PORTS

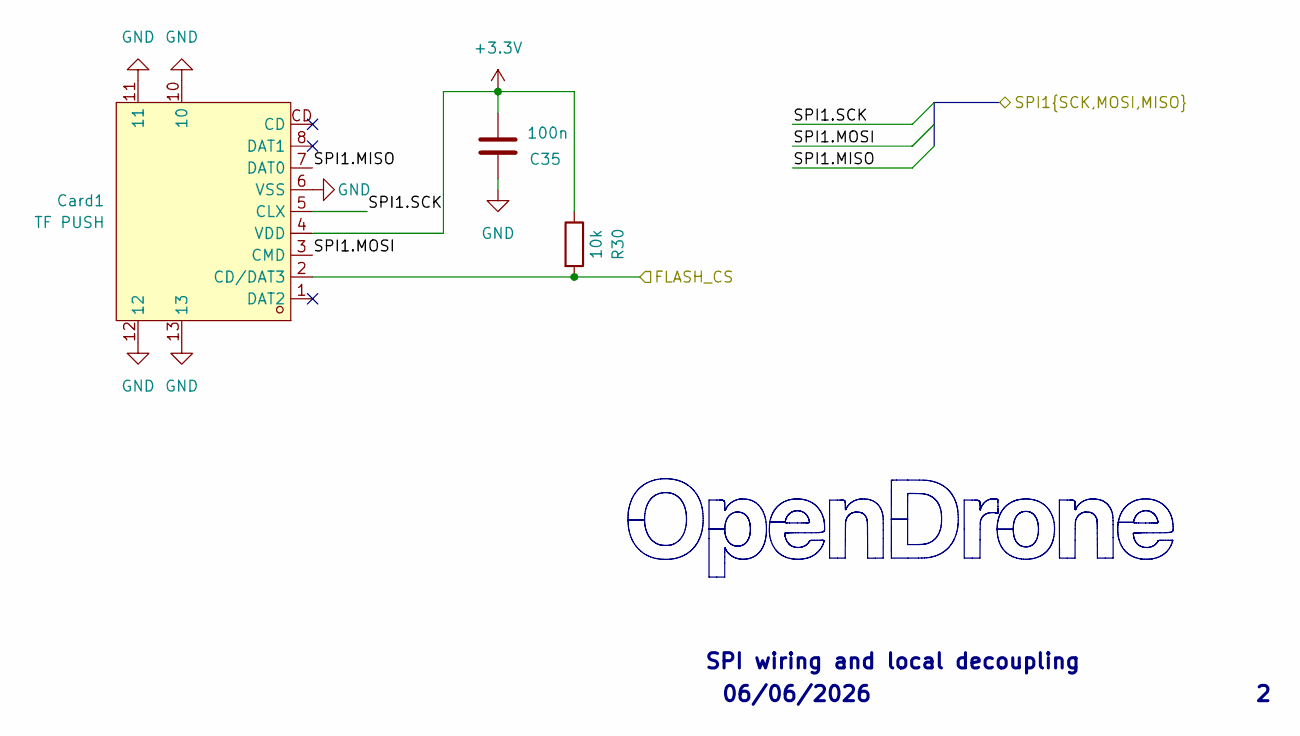
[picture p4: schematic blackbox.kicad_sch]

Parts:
C35: 100n; C_0201_0603Metric; MPN GRM033R61E104KE14D; LCSC C76939
Card1: TF PUSH; TF-SMD_TF-PUSH; MPN TF PUSH; LCSC C393941
R30: 10k; R_0201_0603Metric; MPN RC0201FR-0710KL; LCSC C106225

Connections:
+3.3V: C35.1, Card1.4 (VDD), R30.1; also elsewhere on the board
/BLACKBOX/FLASH_CS: Card1.2 (CD/DAT3), R30.2; also elsewhere on the board
/BLACKBOX/SPI1.MISO: Card1.7 (DAT0); also elsewhere on the board
/BLACKBOX/SPI1.MOSI: Card1.3 (CMD); also elsewhere on the board
/BLACKBOX/SPI1.SCK: Card1.5 (CLX); also elsewhere on the board
GND: C35.2, Card1.6 (VSS), Card1.10, Card1.11, Card1.12, Card1.13; also elsewhere on the board

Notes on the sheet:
SPI wiring and local decoupling
06/06/2026

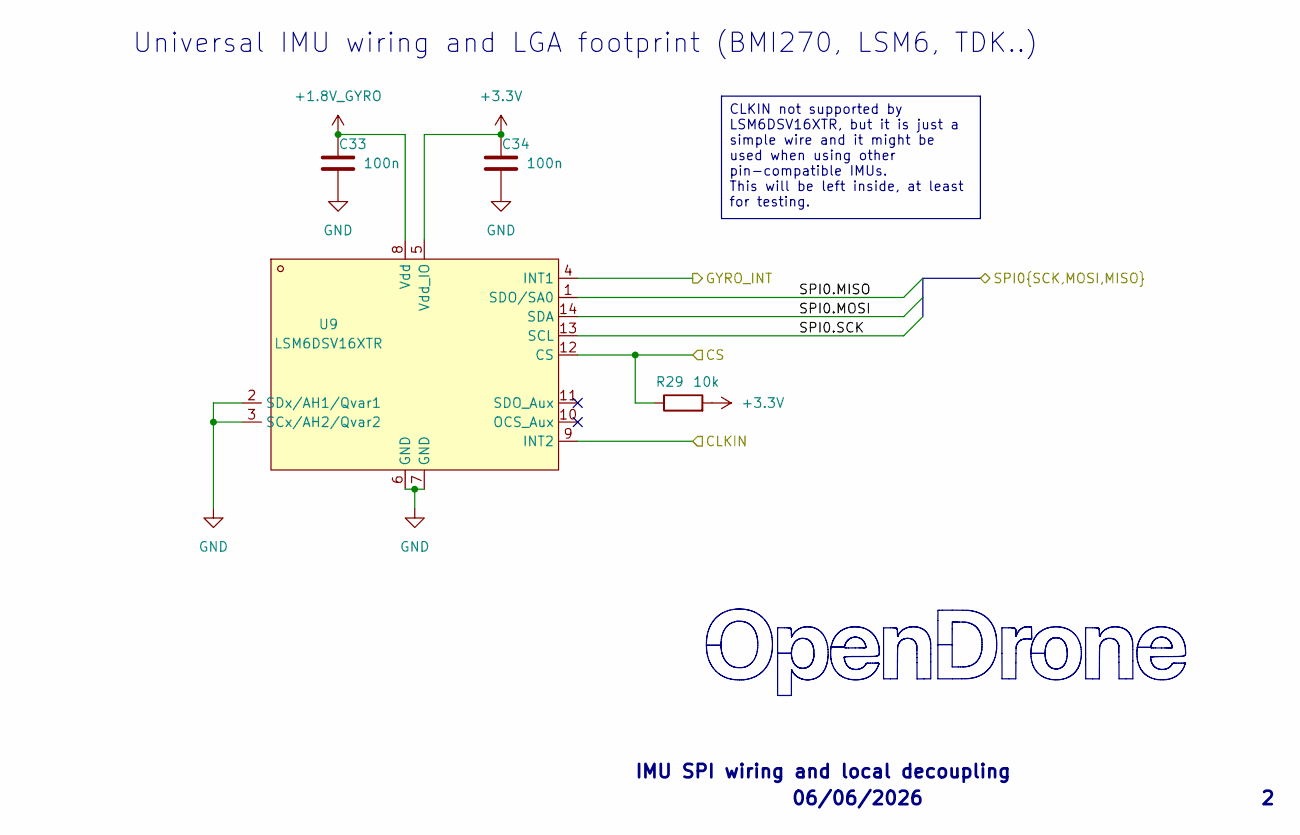
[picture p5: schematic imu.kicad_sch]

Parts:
C33, C34: 100n; C_0201_0603Metric; MPN GRM033R61E104KE14D; LCSC C76939
R29: 10k; R_0201_0603Metric; MPN RC0201FR-0710KL; LCSC C106225
U9: LSM6DSV16XTR; LGA-14_L3.0-W2.5-P0.50-BR; MPN LSM6DSV16XTR; LCSC C5267406

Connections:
+1.8V_GYRO: C33.1, U9.8 (Vdd); also elsewhere on the board
+3.3V: C34.1, R29.2, U9.5 (Vdd_IO); also elsewhere on the board
/IMU/CLKIN: U9.9 (INT2); also elsewhere on the board
/IMU/CS: R29.1, U9.12 (CS); also elsewhere on the board
/IMU/GYRO_INT: U9.4 (INT1); also elsewhere on the board
/IMU/SPI0.MISO: U9.1 (SDO/SA0); also elsewhere on the board
/IMU/SPI0.MOSI: U9.14 (SDA); also elsewhere on the board
/IMU/SPI0.SCK: U9.13 (SCL); also elsewhere on the board
GND: C33.2, C34.2, U9.2 (SDx/AH1/Qvar1), U9.3 (SCx/AH2/Qvar2), U9.6 (GND), U9.7 (GND); also elsewhere on the board

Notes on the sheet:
06/06/2026
IMU SPI wiring and local decoupling
Universal IMU wiring and LGA footprint (BMI270, LSM6, TDK..)
CLKIN not supported by LSM6DSV16XTR, but it is just a simple wire and it might be used when using other pin-compatible IMUs. This will be left inside, at least for testing.

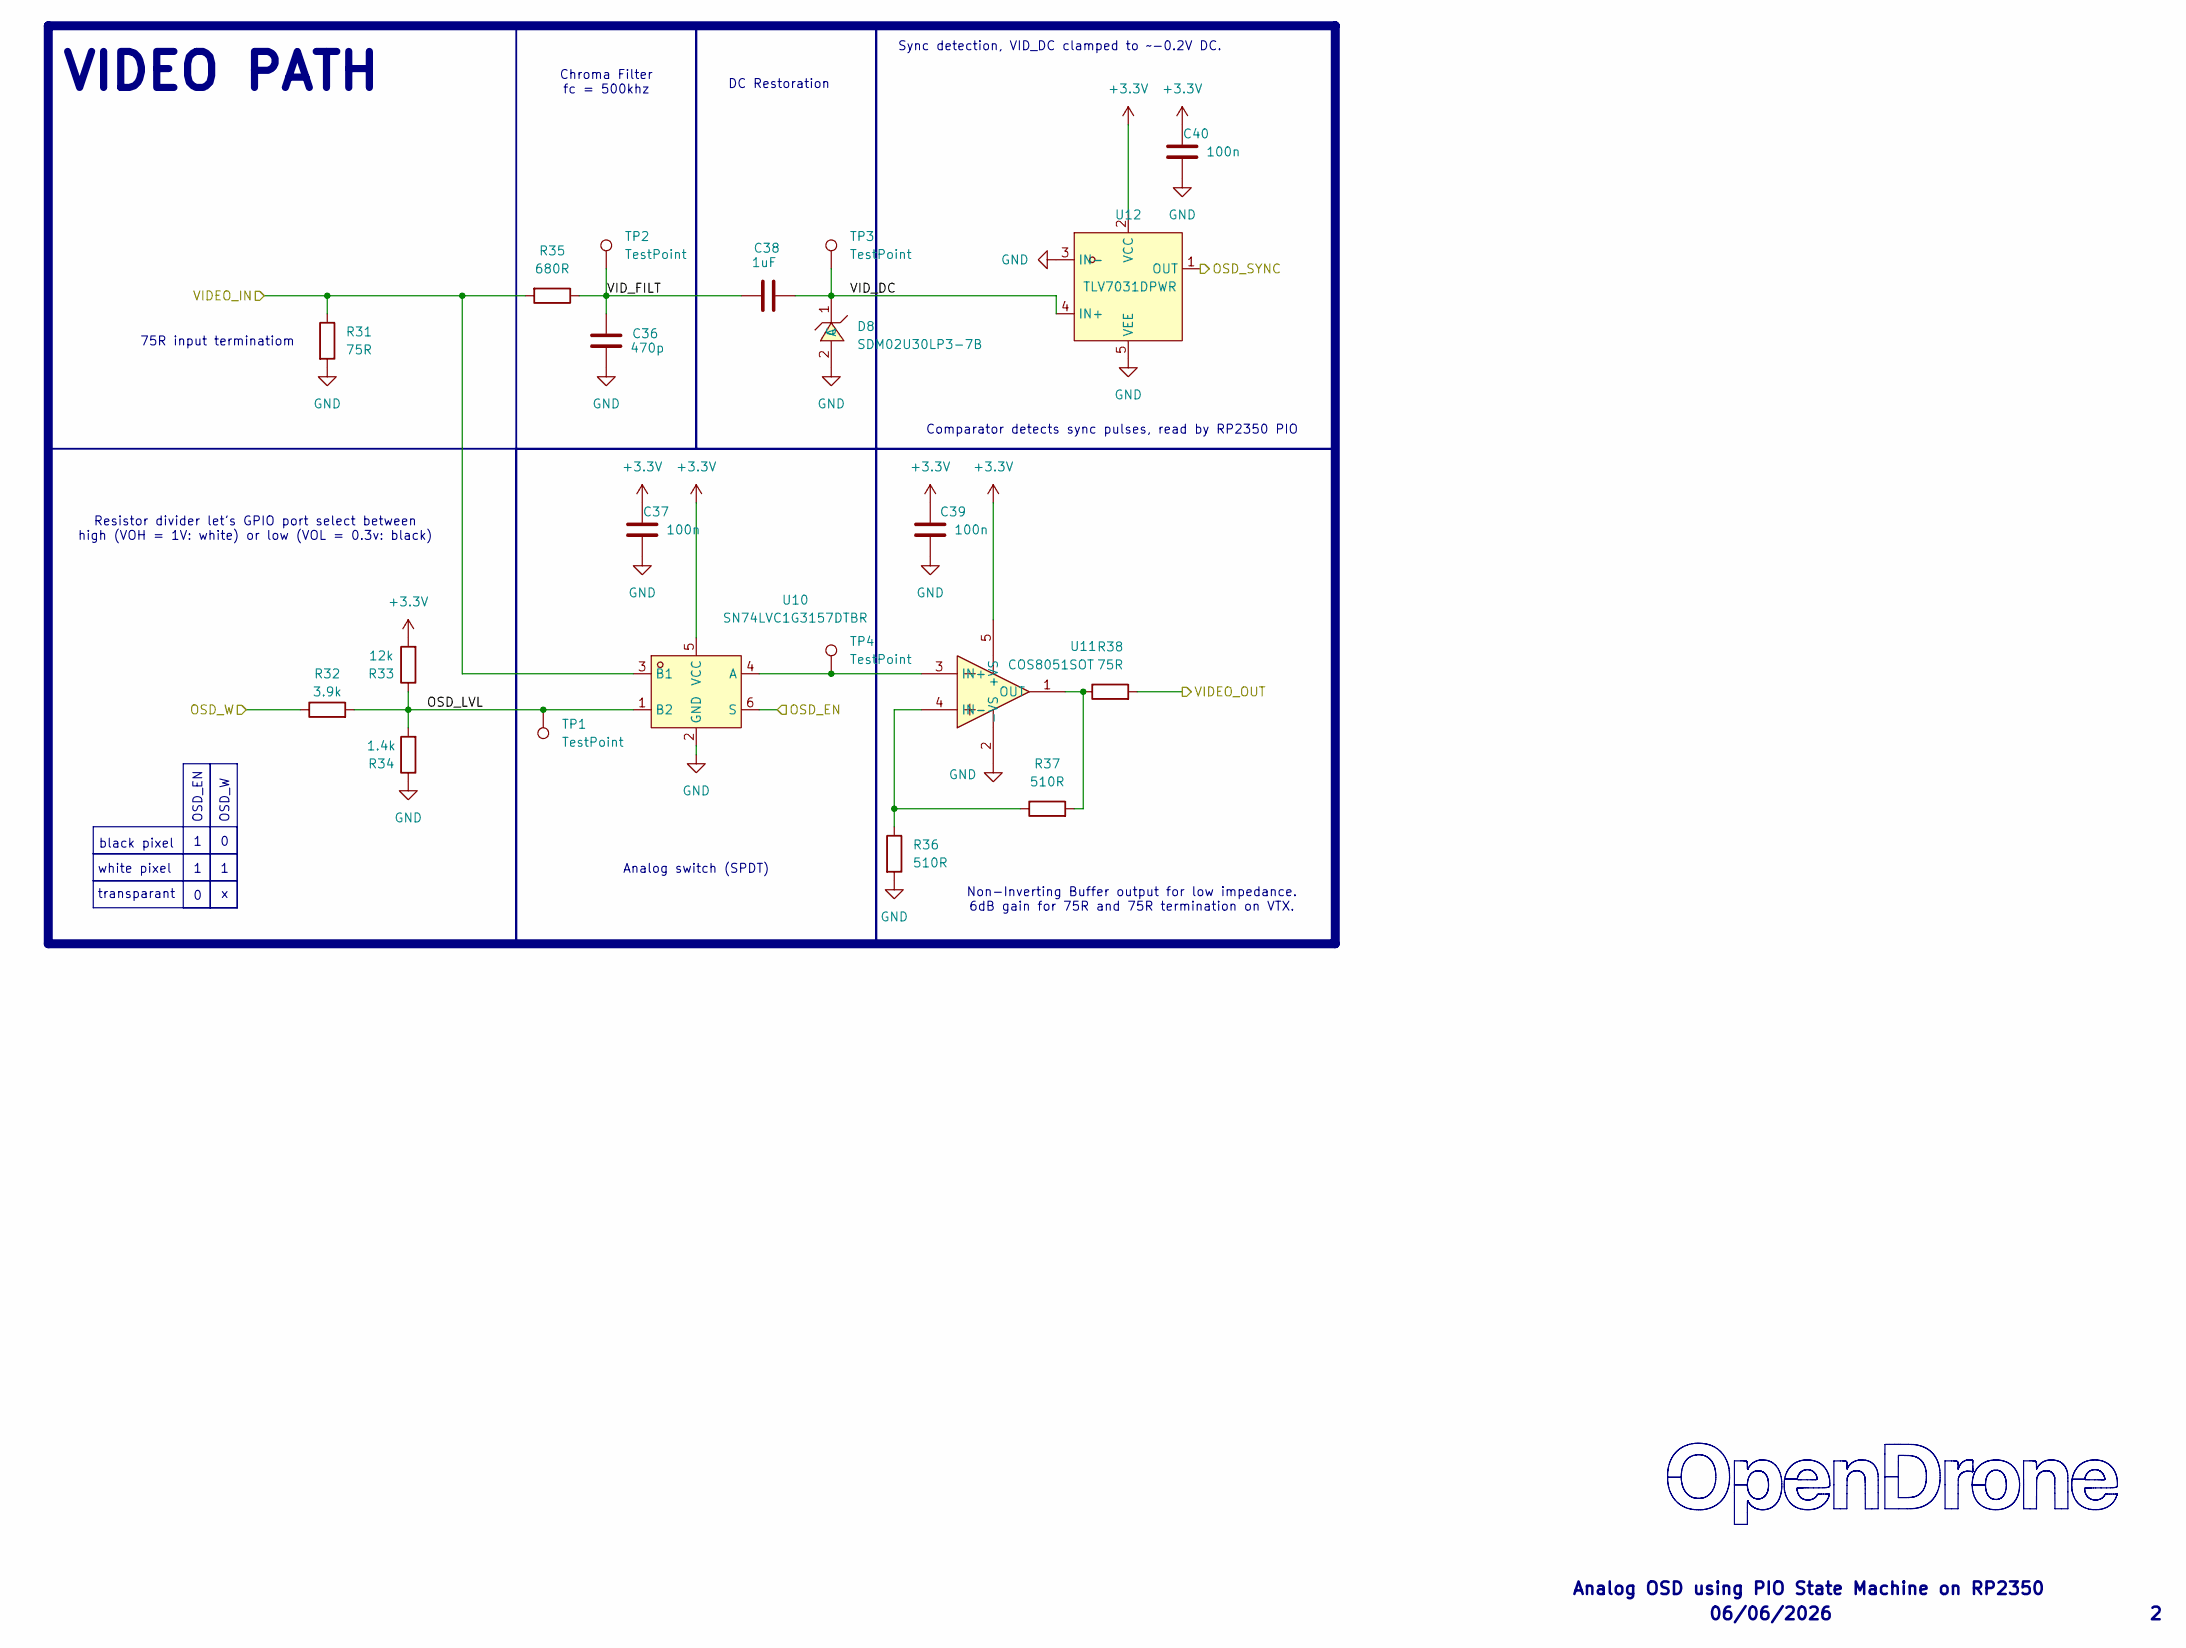
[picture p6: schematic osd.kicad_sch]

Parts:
C36: 470p; C_0201_0603Metric; MPN CC0201JRX7R9BB471; LCSC C526944
C37, C39, C40: 100n; C_0201_0603Metric; MPN GRM033R60J104KE19D; LCSC C76928
C38: 1uF; C_0402_1005Metric; MPN CL05A105KA5NQNC; LCSC C52923
D8: SDM02U30LP3-7B; X3-DFN0603-2_L0.6-W0.3-RD; MPN SDM02U30LP3-7B; LCSC C151629
R31, R38: 75R; R_0201_0603Metric; MPN RC0201FR-0775RL; LCSC C274878
R32: 3.9k; R_0201_0603Metric; MPN RC0201FR-073K9L; LCSC C273280
R33: 12k; R_0201_0603Metric; MPN 0201WMF1202TEE; LCSC C270363
R34: 1.4k; R_0201_0603Metric; MPN 0201WMF1401TEE; LCSC C423739
R35: 680R; R_0201_0603Metric; MPN 0201WMF6800TEE; LCSC C473509
R36, R37: 510R; R_0201_0603Metric; LCSC C57784
TP1, TP2, TP3, TP4: TestPoint; TestPoint_Pad_D1.5mm
U10: SN74LVC1G3157DTBR; X2SON-6_L1.0-W0.8-BL; MPN SN74LVC1G3157DTBR; LCSC C2673087
U11: COS8051SOT; SOT-23-5_L3.0-W1.7-P0.95-LS2.8-BR; MPN COS8051SOT; LCSC C7463385
U12: TLV7031DPWR; X2SON-4_L0.8-W0.8-P0.48-TL-A; MPN TLV7031DPWR; LCSC C2876045

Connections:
+3.3V: C37.1, C39.1, C40.1, R33.2, U10.5 (VCC), U11.5 (+VS), U12.2 (VCC); also elsewhere on the board
/OSD/OSD_EN: U10.6 (S); also elsewhere on the board
/OSD/OSD_LVL: R32.2, R33.1, R34.2, TP1.1 (1_1), U10.1 (B2)
/OSD/OSD_SYNC: U12.1 (OUT); also elsewhere on the board
/OSD/OSD_W: R32.1; also elsewhere on the board
/OSD/VIDEO_IN: R31.1, R35.2, U10.3 (B1); also elsewhere on the board
/OSD/VIDEO_OUT: R38.2; also elsewhere on the board
/OSD/VID_DC: C38.2, D8.1 (C), TP3.1 (1_1), U12.4 (IN+)
/OSD/VID_FILT: C36.1, C38.1, R35.1, TP2.1 (1_1)
GND: C36.2, C37.2, C39.2, C40.2, D8.2 (A), R31.2, R34.1, R36.2, U10.2 (GND), U11.2 (-VS), U12.3 (IN-), U12.5 (VEE); also elsewhere on the board
unnamed: TP4.1 (1_1), U10.4 (A), U11.3 (IN+)
unnamed: R36.1, R37.1, U11.4 (IN-)
unnamed: R37.2, R38.1, U11.1 (OUT)

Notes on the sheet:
black pixel
Comparator detects sync pulses, read by RP2350 PIO
06/06/2026
Analog OSD using PIO State Machine on RP2350
Sync detection, VID_DC clamped to ~-0.2V DC.
Non-Inverting Buffer output for low impedance. 6dB gain for 75R and 75R termination on VTX.
white pixel
75R input terminatiom
OSD_W
Chroma Filter fc = 500khz
VIDEO PATH
Analog switch (SPDT)
OSD_EN
transparant
DC Restoration
Resistor divider let's GPIO port select between high (VOH = 1V: white) or low (VOL = 0.3v: black)

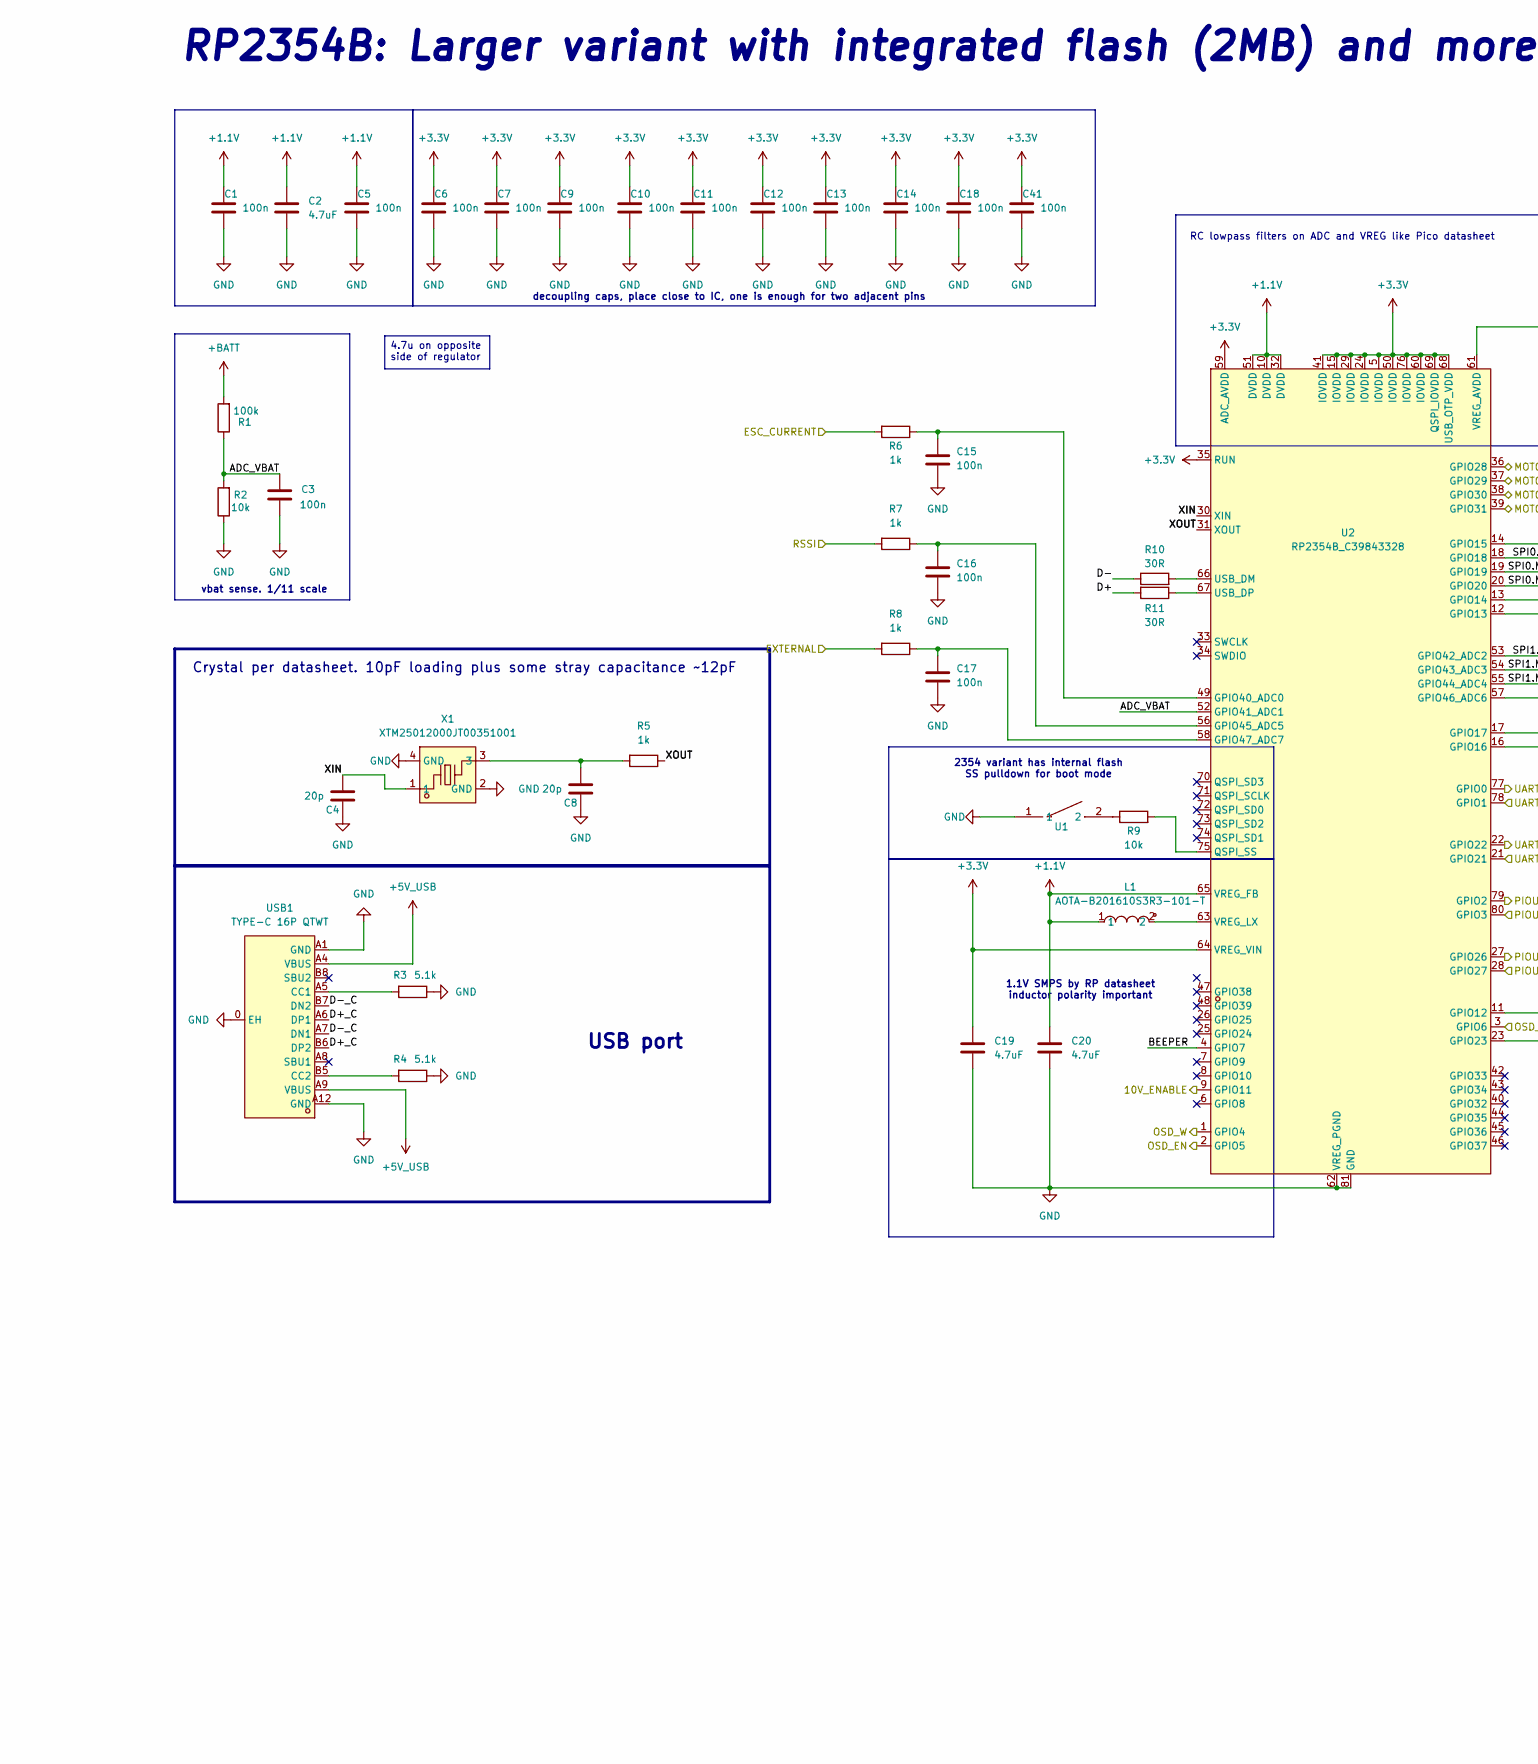
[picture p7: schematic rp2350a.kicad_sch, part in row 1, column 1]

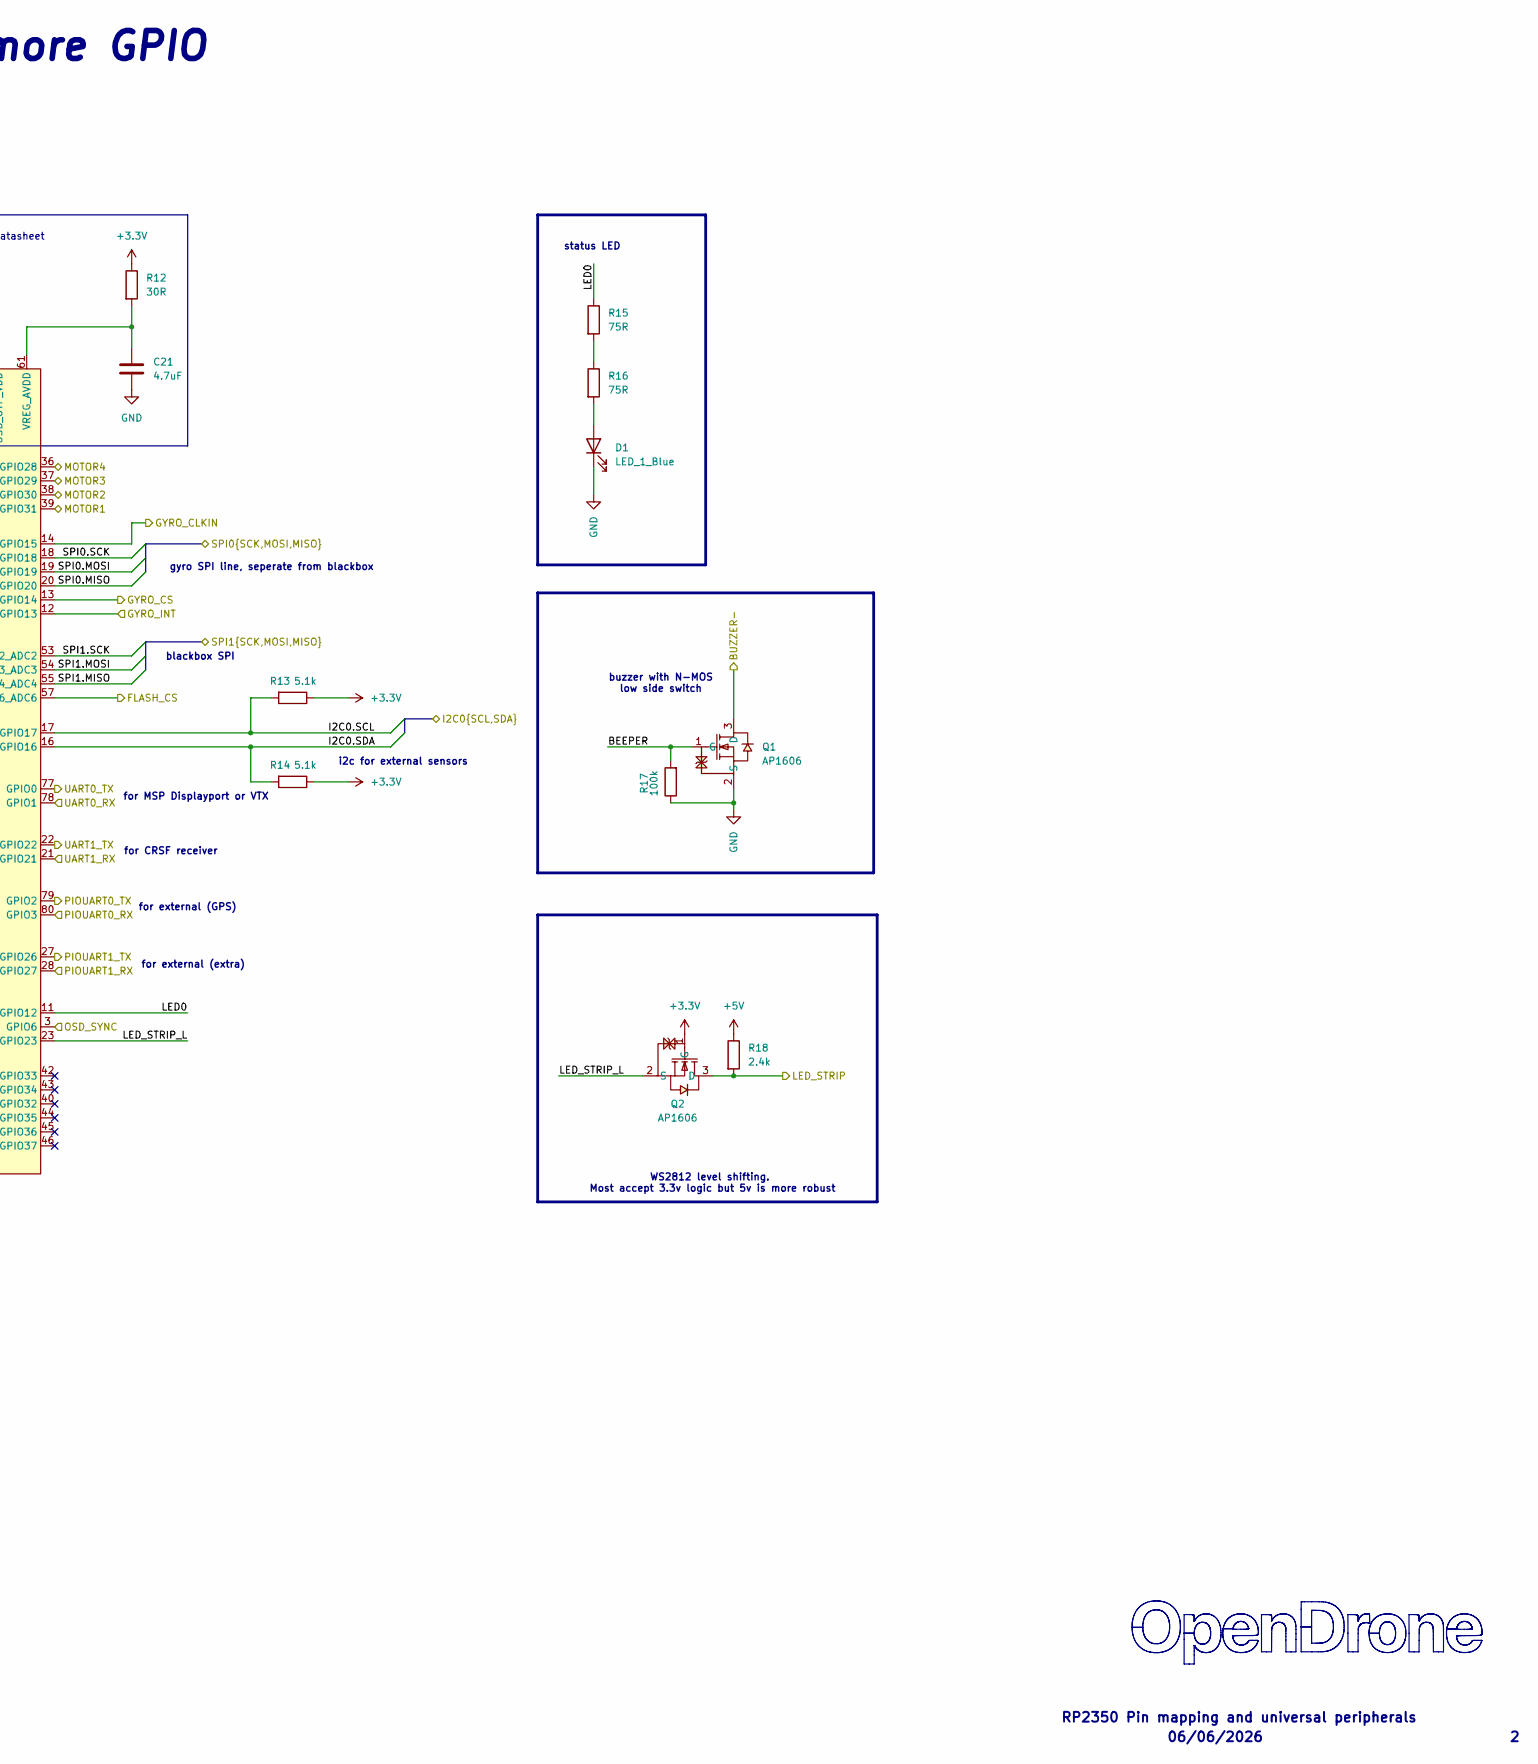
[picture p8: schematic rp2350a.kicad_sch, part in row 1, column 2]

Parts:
C1, C3, C5, C6, C7, C9, C10, C11, C12, C13, C14, C15, C16, C17, C18, C41: 100n; C_0201_0603Metric; MPN GRM033R61E104KE14D; LCSC C76939
C2, C19, C20, C21: 4.7uF; C_0402_1005Metric; MPN CL05A475MP5NRNC; LCSC C23733
C4, C8: 20p; C_0201_0603Metric; MPN GRM0335C1H200JA01D; LCSC C76923
D1: LED_1_Blue; LED_0402_1005Metric; MPN XL-1005UBC; LCSC C22355736
L1: AOTA-B201610S3R3-101-T; IND-SMD_L2.0-W1.6_AOTA-B201610S3R3-101-T; MPN AOTA-B201610S3R3-101-T; LCSC C42411119
Q1, Q2: AP1606; DFN-3L_L1.0-W0.6-P0.65-BR; MPN AP1606; LCSC C2849580
R1, R17: 100k; R_0201_0603Metric; MPN 0201WMF1003TEE; LCSC C270364
R2, R9: 10k; R_0201_0603Metric; MPN RC0201FR-0710KL; LCSC C106225
R3, R4, R13, R14: 5.1k; R_0201_0603Metric; MPN 0201WMF5101TEE; LCSC C270344
R5, R6, R7, R8: 1k; R_0201_0603Metric; MPN 0201WMF1001TEE; LCSC C270365
R10, R11, R12: 30R; R_0201_0603Metric; MPN NQ01WMJ0300TEE; LCSC C778391
R15, R16: 75R; R_0201_0603Metric; MPN RC0201FR-0775RL; LCSC C274878
R18: 2.4k; R_0201_0603Metric; LCSC C166281
U1: TS2306A 240GF MSM 9_C2976675; SW-SMD_4P-L3.0-W2.0-P0.85-LS3.5; MPN TS2306A 240gf MSM 9; LCSC C2976675
U2: RP2354B_C39843328; QFN-80_L10.0-W10.0-P0.40-TL-EP3.4; MPN RP2354B; LCSC C39843328
USB1: TYPE-C 16P QTWT; USB-TYPE-C-SMD_TYPE-C-16P-QTWT; MPN TYPE-C 16P QTWT; LCSC C5187472
X1: XTM25012000JT00351001; CRYSTAL-SMD_4P-L2.5-W2.0-BL-A; MPN XTM25012000JT00351001; LCSC C37635340

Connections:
+1.1V: C1.1, C2.1, C5.1, C20.1, L1.1, U2.10 (DVDD), U2.32 (DVDD), U2.51 (DVDD), U2.65 (VREG_FB)
+3.3V: C6.1, C7.1, C9.1, C10.1, C11.1, C12.1, C13.1, C14.1, C18.1, C19.1, C41.1, Q2.1 (G), R12.1, R13.1, R14.1, U2.5 (IOVDD), U2.15 (IOVDD), U2.24 (IOVDD), U2.29 (IOVDD), U2.35 (RUN), U2.41 (IOVDD), U2.50 (IOVDD), U2.59 (ADC_AVDD), U2.60 (IOVDD), U2.64 (VREG_VIN), U2.68 (USB_OTP_VDD), U2.69 (QSPI_IOVDD), U2.76 (IOVDD); also elsewhere on the board
+5V: R18.1; also elsewhere on the board
+5V_USB: USB1.A4 (VBUS), USB1.A9 (VBUS); also elsewhere on the board
+BATT: R1.2; also elsewhere on the board
/BLACKBOX/FLASH_CS: U2.57 (GPIO46_ADC6); also elsewhere on the board
/BLACKBOX/SPI1.MISO: U2.55 (GPIO44_ADC4); also elsewhere on the board
/BLACKBOX/SPI1.MOSI: U2.54 (GPIO43_ADC3); also elsewhere on the board
/BLACKBOX/SPI1.SCK: U2.53 (GPIO42_ADC2); also elsewhere on the board
/IMU/CLKIN: U2.14 (GPIO15); also elsewhere on the board
/IMU/CS: U2.13 (GPIO14); also elsewhere on the board
/IMU/GYRO_INT: U2.12 (GPIO13); also elsewhere on the board
/IMU/SPI0.MISO: U2.20 (GPIO20); also elsewhere on the board
/IMU/SPI0.MOSI: U2.19 (GPIO19); also elsewhere on the board
/IMU/SPI0.SCK: U2.18 (GPIO18); also elsewhere on the board
/OSD/OSD_EN: U2.2 (GPIO5); also elsewhere on the board
/OSD/OSD_SYNC: U2.3 (GPIO6); also elsewhere on the board
/OSD/OSD_W: U2.1 (GPIO4); also elsewhere on the board
/PADS/ADC2: R8.2; also elsewhere on the board
/PADS/BUZZER-: Q1.3 (D); also elsewhere on the board
/PADS/CURRENT: R6.2; also elsewhere on the board
/PADS/I2C0.SCL: R13.2, U2.17 (GPIO17); also elsewhere on the board
/PADS/I2C0.SDA: R14.2, U2.16 (GPIO16); also elsewhere on the board
/PADS/LED_STRIP: Q2.3 (D), R18.2; also elsewhere on the board
/PADS/M1: U2.39 (GPIO31); also elsewhere on the board
/PADS/M2: U2.38 (GPIO30); also elsewhere on the board
/PADS/M3: U2.37 (GPIO29); also elsewhere on the board
/PADS/M4: U2.36 (GPIO28); also elsewhere on the board
/PADS/PIOUART0_RX: U2.80 (GPIO3); also elsewhere on the board
/PADS/PIOUART0_TX: U2.79 (GPIO2); also elsewhere on the board
/PADS/PIOUART1_TX: U2.27 (GPIO26); also elsewhere on the board
/PADS/PU1RX: U2.28 (GPIO27); also elsewhere on the board
/PADS/RSSI: R7.2; also elsewhere on the board
/PADS/U1RX: U2.21 (GPIO21); also elsewhere on the board
/PADS/UART0_RX: U2.78 (GPIO1); also elsewhere on the board
/PADS/UART0_TX: U2.77 (GPIO0); also elsewhere on the board
/PADS/UART1_TX: U2.22 (GPIO22); also elsewhere on the board
/POWER/10V_ENABLE: U2.9 (GPIO11); also elsewhere on the board
/RP2350A/ADC_VBAT: C3.2, R1.1, R2.2, U2.52 (GPIO41_ADC1)
/RP2350A/BEEPER: Q1.1 (G), R17.2, U2.4 (GPIO7)
/RP2350A/D+: R11.2
/RP2350A/D+_C: USB1.A6 (DP1), USB1.B6 (DP2)
/RP2350A/D-: R10.1
/RP2350A/D-_C: USB1.A7 (DN1), USB1.B7 (DN2)
/RP2350A/LED0: R15.1, U2.11 (GPIO12)
/RP2350A/LED_STRIP_L: Q2.2 (S), U2.23 (GPIO23)
/RP2350A/XIN: C4.2, U2.30 (XIN), X1.1
/RP2350A/XOUT: R5.1, U2.31 (XOUT)
GND: C1.2, C2.2, C3.1, C4.1, C5.2, C6.2, C7.2, C8.1, C9.2, C10.2, C11.2, C12.2, C13.2, C14.2, C15.2, C16.2, C17.2, C18.2, C19.2, C20.2, C21.2, C41.2, D1.1 (K), Q1.2 (S), R2.1, R3.1, R4.1, R17.1, U1.1, U2.62 (VREG_PGND), U2.81 (GND), USB1.0 (EH), USB1.A1 (GND), USB1.A12 (GND), X1.2 (GND), X1.4 (GND); also elsewhere on the board
unnamed: C8.2, R5.2, X1.3
unnamed: D1.2 (A), R16.2
unnamed: R9.1, U1.2
unnamed: R15.2, R16.1
unnamed: C15.1, R6.1, U2.49 (GPIO40_ADC0)
unnamed: C16.1, R7.1, U2.56 (GPIO45_ADC5)
unnamed: C17.1, R8.1, U2.58 (GPIO47_ADC7)
unnamed: R9.2, U2.75 (QSPI_SS)
unnamed: R10.2, U2.66 (USB_DM)
unnamed: R11.1, U2.67 (USB_DP)
unnamed: C21.1, R12.2, U2.61 (VREG_AVDD)
unnamed: L1.2, U2.63 (VREG_LX)
unnamed: R3.2, USB1.A5 (CC1)
unnamed: R4.2, USB1.B5 (CC2)

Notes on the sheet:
RP2350 Pin mapping and universal peripherals
vbat sense. 1/11 scale
RP2354B: Larger variant with integrated flash (2MB) and more GPIO
blackbox SPI
06/06/2026
for MSP Displayport or VTX
2354 variant has internal flash SS pulldown for boot mode
for CRSF receiver
gyro SPI line, seperate from blackbox
decoupling caps, place close to IC, one is enough for two adjacent pins
for external (extra)
Crystal per datasheet. 10pF loading plus some stray capacitance ~12pF
for external (GPS)
i2c for external sensors
WS2812 level shifting. Most accept 3.3v logic but 5v is more robust
status LED
RC lowpass filters on ADC and VREG like Pico datasheet
USB port
1.1V SMPS by RP datasheet inductor polarity important
buzzer with N-MOS low side switch
4.7u on opposite side of regulator

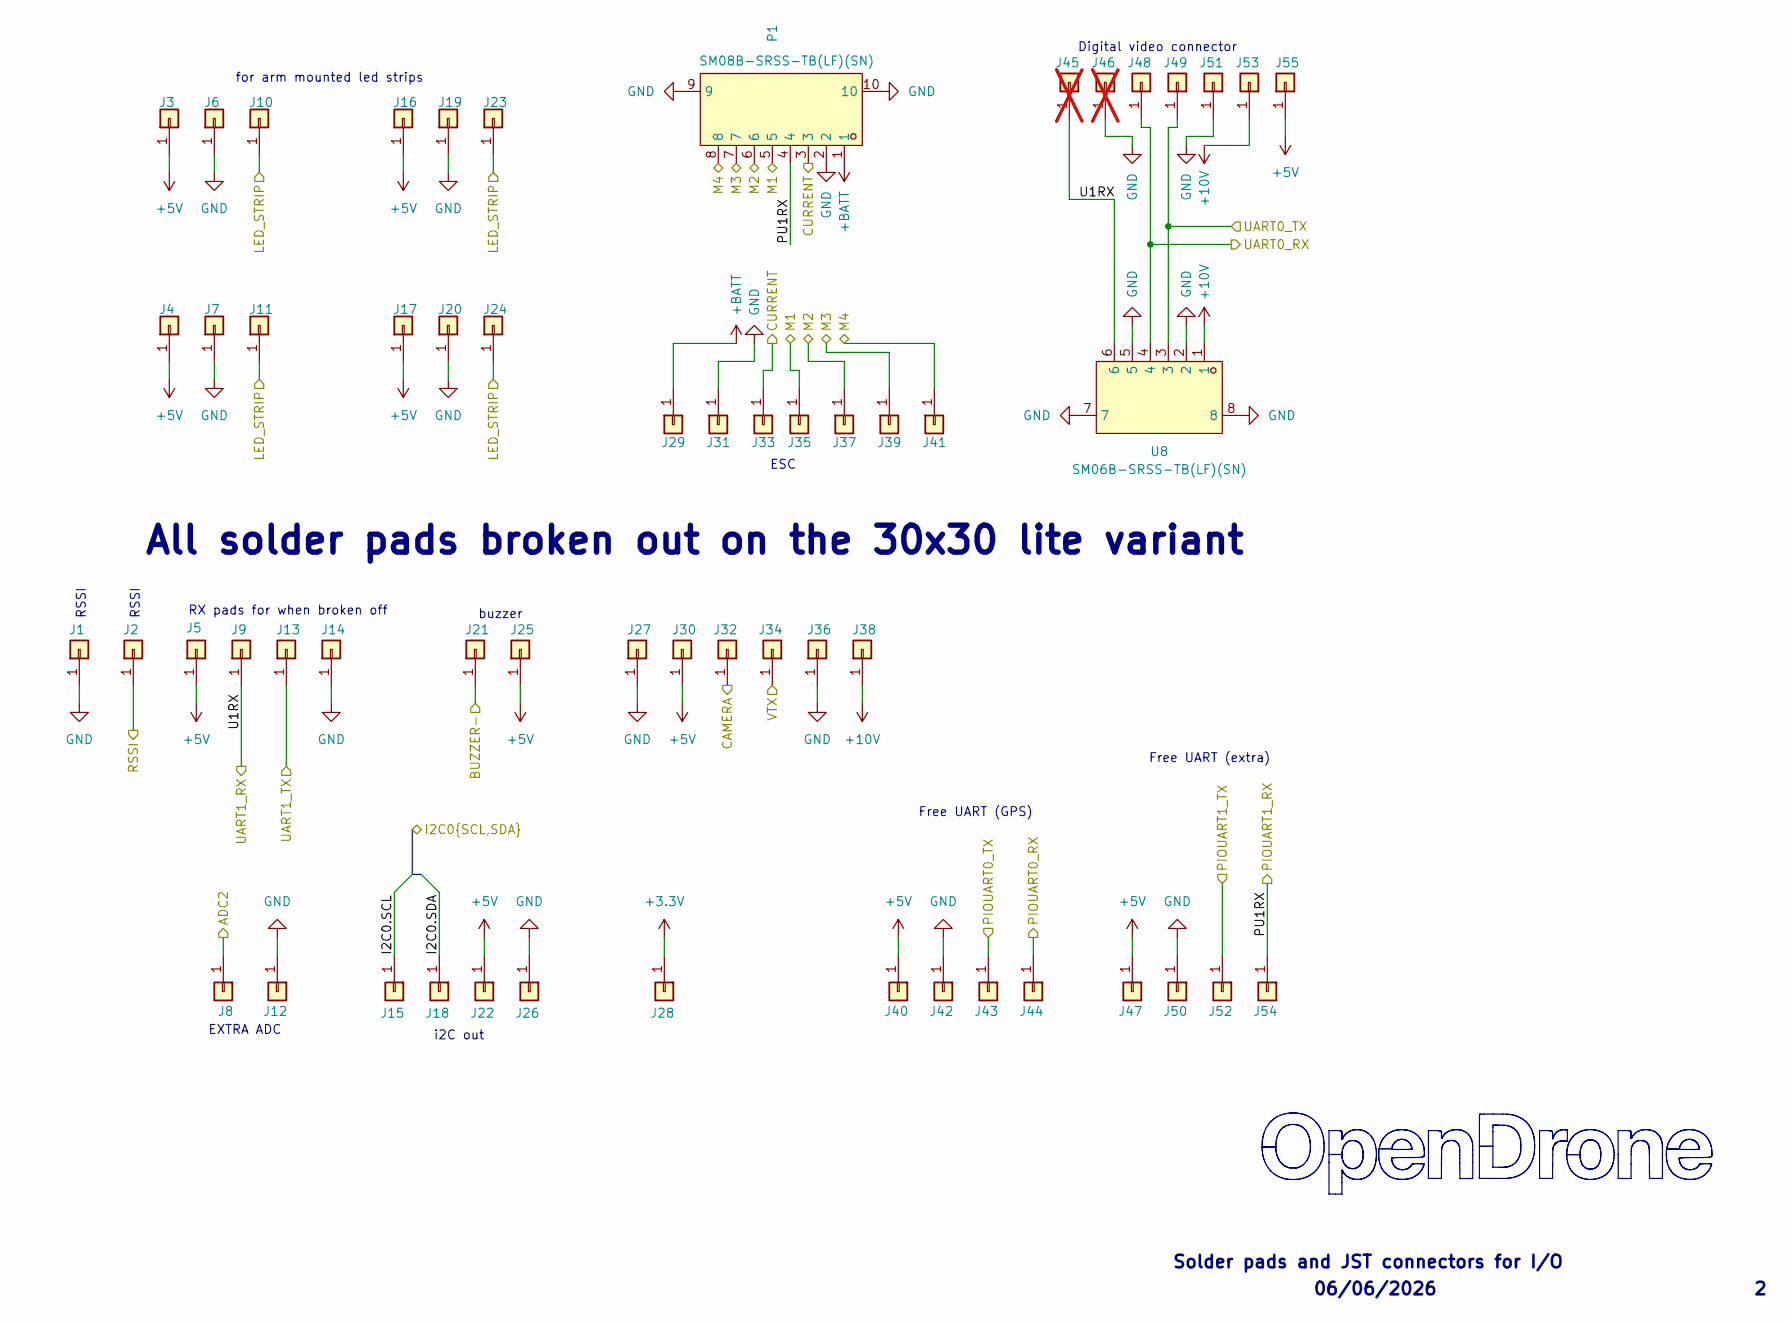
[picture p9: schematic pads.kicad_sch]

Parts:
J1, J2, J3, J4, J5, J6, J7, J8, J9, J10, J11, J12, J13, J14, J15, J16, J17, J18, J19, J20, J21, J22, J23, J24, J25, J26, J27, J28, J29, J30, J31, J32, J33, J34, J35, J36, J37, J38, J39, J40, J41, J42, J43, J44, J47, J48, J49, J50, J51, J52, J53, J54, J55: 5V; small_pad
J45, J46: 5V; small_pad; not fitted
P1: SM08B-SRSS-TB(LF)(SN); CONN-TH_SM08B-SRSS-TB-LF-SN; MPN SM08B-SRSS-TB(LF)(SN); LCSC C160407
U8: SM06B-SRSS-TB(LF)(SN); CONN-SMD_SM06B-SRSS-TB-LF-SN; MPN SM06B-SRSS-TB(LF)(SN); LCSC C160405

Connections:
+3.3V: J28.1 (Pin_1_1); also elsewhere on the board
+5V: J3.1 (Pin_1_1), J4.1 (Pin_1_1), J5.1 (Pin_1_1), J16.1 (Pin_1_1), J17.1 (Pin_1_1), J22.1 (Pin_1_1), J25.1 (Pin_1_1), J30.1 (Pin_1_1), J40.1 (Pin_1_1), J47.1 (Pin_1_1), J55.1 (Pin_1_1); also elsewhere on the board
+10V: J38.1 (Pin_1_1), J53.1 (Pin_1_1), U8.1; also elsewhere on the board
+BATT: J29.1 (Pin_1_1), P1.1; also elsewhere on the board
/OSD/VIDEO_IN: J32.1 (Pin_1_1); also elsewhere on the board
/OSD/VIDEO_OUT: J34.1 (Pin_1_1); also elsewhere on the board
/PADS/ADC2: J8.1 (Pin_1_1); also elsewhere on the board
/PADS/BUZZER-: J21.1 (Pin_1_1); also elsewhere on the board
/PADS/CURRENT: J33.1 (Pin_1_1), P1.3; also elsewhere on the board
/PADS/I2C0.SCL: J15.1 (Pin_1_1); also elsewhere on the board
/PADS/I2C0.SDA: J18.1 (Pin_1_1); also elsewhere on the board
/PADS/LED_STRIP: J10.1 (Pin_1_1), J11.1 (Pin_1_1), J23.1 (Pin_1_1), J24.1 (Pin_1_1); also elsewhere on the board
/PADS/M1: J35.1 (Pin_1_1), P1.5; also elsewhere on the board
/PADS/M2: J37.1 (Pin_1_1), P1.6; also elsewhere on the board
/PADS/M3: J39.1 (Pin_1_1), P1.7; also elsewhere on the board
/PADS/M4: J41.1 (Pin_1_1), P1.8; also elsewhere on the board
/PADS/PIOUART0_RX: J44.1 (Pin_1_1); also elsewhere on the board
/PADS/PIOUART0_TX: J43.1 (Pin_1_1); also elsewhere on the board
/PADS/PIOUART1_TX: J52.1 (Pin_1_1); also elsewhere on the board
/PADS/PU1RX: J54.1 (Pin_1_1), P1.4; also elsewhere on the board
/PADS/RSSI: J2.1 (Pin_1_1); also elsewhere on the board
/PADS/U1RX: J9.1 (Pin_1_1), J45.1, U8.6; also elsewhere on the board
/PADS/UART0_RX: J48.1 (Pin_1_1), U8.4; also elsewhere on the board
/PADS/UART0_TX: J49.1 (Pin_1_1), U8.3; also elsewhere on the board
/PADS/UART1_TX: J13.1 (Pin_1_1); also elsewhere on the board
GND: J1.1 (Pin_1_1), J6.1 (Pin_1_1), J7.1 (Pin_1_1), J12.1 (Pin_1_1), J14.1 (Pin_1_1), J19.1 (Pin_1_1), J20.1 (Pin_1_1), J26.1 (Pin_1_1), J27.1 (Pin_1_1), J31.1 (Pin_1_1), J36.1 (Pin_1_1), J42.1 (Pin_1_1), J46.1, J50.1 (Pin_1_1), J51.1 (Pin_1_1), P1.2, P1.9, P1.10, U8.2, U8.5, U8.7, U8.8; also elsewhere on the board

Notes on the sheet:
06/06/2026
RSSI
Free UART (GPS)
Solder pads and JST connectors for I/O
i2C out
All solder pads broken out on the 30x30 lite variant
Free UART (extra)
buzzer
RX pads for when broken off
ESC
Digital video connector
EXTRA ADC
for arm mounted led strips

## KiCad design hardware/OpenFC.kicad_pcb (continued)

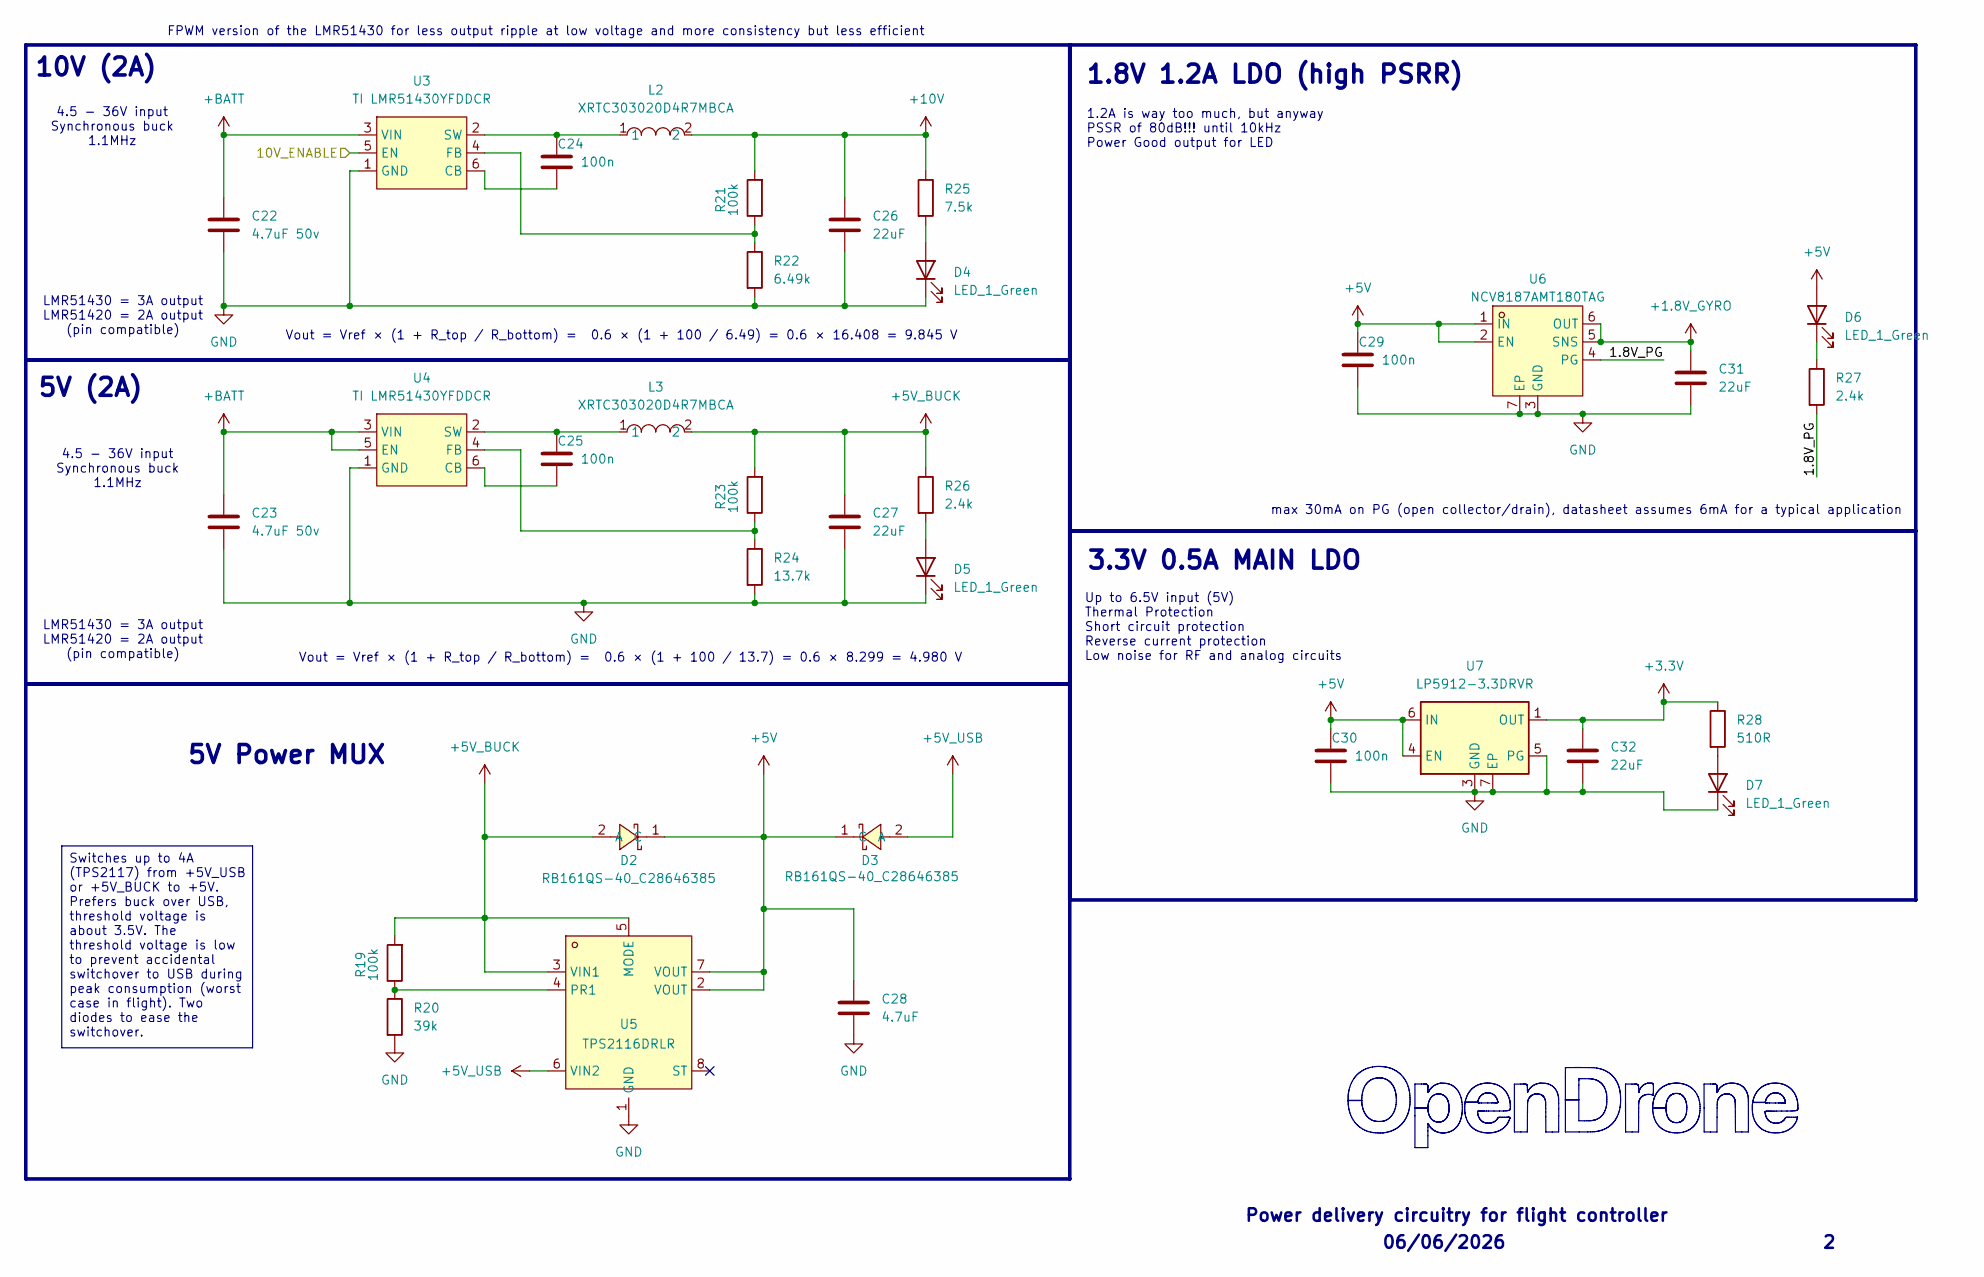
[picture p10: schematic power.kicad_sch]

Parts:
C22, C23: 4.7uF 50v; C_0805_2012Metric; MPN CL21A475KBQNNNE; LCSC C98192
C24, C25, C29, C30: 100n; C_0201_0603Metric; MPN GRM033R61E104KE14D; LCSC C76939
C26, C27: 22uF; C_0603_1608Metric; MPN CL10A226MO7JZNC; LCSC C2762594
C28: 4.7uF; C_0402_1005Metric; MPN CL05A475MP5NRNC; LCSC C23733
C31, C32: 22uF; C_0402_1005Metric; MPN CL05A226MQ5QUNC; LCSC C105226
D2, D3: RB161QS-40_C28646385; SOD-882_L1.0-W0.6-RD; MPN RB161QS-40; LCSC C28646385
D4, D5, D6, D7: LED_1_Green; LED_0402_1005Metric; MPN XL-1005UGC; LCSC C965793
L2, L3: XRTC303020D4R7MBCA; IND-SMD_L3.0-W3.0_AFE303020S; MPN XRTC303020D4R7MBCA; LCSC C39846837
R19, R21, R23: 100k; R_0201_0603Metric; MPN 0201WMF1003TEE; LCSC C270364
R20: 39k; R_0201_0603Metric; MPN 0201WMF3902TEE; LCSC C473053
R22: 6.49k; R_0201_0603Metric; LCSC C2107920
R24: 13.7k; R_0201_0603Metric; MPN RC-01W1372FT; LCSC C320695
R25: 7.5k; R_0201_0603Metric; LCSC C474437
R26, R27: 2.4k; R_0201_0603Metric; LCSC C166281
R28: 510R; R_0201_0603Metric; LCSC C57784
U3, U4: TI LMR51430YFDDCR; SOT-23-6_L2.9-W1.6-P0.95-LS2.9-BL; MPN TI LMR51430YFDDCR; LCSC C5219261
U5: TPS2116DRLR; SOT-583-8_L2.1-W1.6-P0.50-LS1.6-BL; MPN TPS2116DRLR; LCSC C3235557
U6: NCV8187AMT180TAG; WDFN-6_L2.0-W2.0-P0.65-BL-EP; MPN NCV8187AMT180TAG; LCSC C893189
U7: LP5912-3.3DRVR; WSON-6-1EP_2x2mm_P0.65mm_EP1x1.6mm; MPN LP5912-3.3DRVR; LCSC C524780

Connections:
+1.8V_GYRO: C31.1, U6.5 (SNS), U6.6 (OUT); also elsewhere on the board
+3.3V: C32.1, R28.1, U7.1 (OUT); also elsewhere on the board
+5V: C28.1, C29.1, C30.1, D2.1 (C), D3.1 (C), D6.2 (A), U5.2 (VOUT), U5.7 (VOUT), U6.1 (IN), U6.2 (EN), U7.4 (EN), U7.6 (IN); also elsewhere on the board
+5V_BUCK: C27.1, D2.2 (A), L3.2, R19.2, R23.2, R26.1, U5.3 (VIN1), U5.5 (MODE)
+5V_USB: D3.2 (A), U5.6 (VIN2); also elsewhere on the board
+10V: C26.1, L2.2, R21.2, R25.1; also elsewhere on the board
+BATT: C22.1, C23.1, U3.3 (VIN), U4.3 (VIN), U4.5 (EN); also elsewhere on the board
/POWER/1.8V_PG: R27.2, U6.4 (PG)
/POWER/10V_ENABLE: U3.5 (EN); also elsewhere on the board
GND: C22.2, C23.2, C26.2, C27.2, C28.2, C29.2, C30.2, C31.2, C32.2, D4.1 (K), D5.1 (K), D7.1 (K), R20.2, R22.2, R24.2, U3.1 (GND), U4.1 (GND), U5.1 (GND), U6.3 (GND), U6.7 (EP), U7.3 (GND), U7.5 (PG), U7.7 (EP); also elsewhere on the board
unnamed: D4.2 (A), R25.2
unnamed: D5.2 (A), R26.2
unnamed: D6.1 (K), R27.1
unnamed: D7.2 (A), R28.2
unnamed: C24.2, U3.6 (CB)
unnamed: R21.1, R22.1, U3.4 (FB)
unnamed: C24.1, L2.1, U3.2 (SW)
unnamed: C25.2, U4.6 (CB)
unnamed: R23.1, R24.1, U4.4 (FB)
unnamed: C25.1, L3.1, U4.2 (SW)
unnamed: R19.1, R20.1, U5.4 (PR1)

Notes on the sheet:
5V Power MUX
1.2A is way too much, but anyway PSSR of 80dB!!! until 10kHz Power Good output for LED
max 30mA on PG (open collector/drain), datasheet assumes 6mA for a typical application
4.5 - 36V input Synchronous buck 1.1MHz
Power delivery circuitry for flight controller
06/06/2026
LMR51430 = 3A output LMR51420 = 2A output (pin compatible)
Vout = Vref × (1 + R_top / R_bottom) = 0.6 × (1 + 100 / 6.49) = 0.6 × 16.408 = 9.845 V
Vout = Vref × (1 + R_top / R_bottom) = 0.6 × (1 + 100 / 13.7) = 0.6 × 8.299 = 4.980 V
Up to 6.5V input (5V) Thermal Protection Short circuit protection Reverse current protection Low noise for RF and analog circuits
5V (2A)
1.8V 1.2A LDO (high PSRR)
FPWM version of the LMR51430 for less output ripple at low voltage and more consistency but less efficient
10V (2A)
3.3V 0.5A MAIN LDO
Switches up to 4A (TPS2117) from +5V_USB or +5V_BUCK to +5V. Prefers buck over USB, threshold voltage is about 3.5V. The threshold voltage is low to prevent accidental switchover to USB during peak consumption (worst case in flight). Two diodes to ease the switchover.

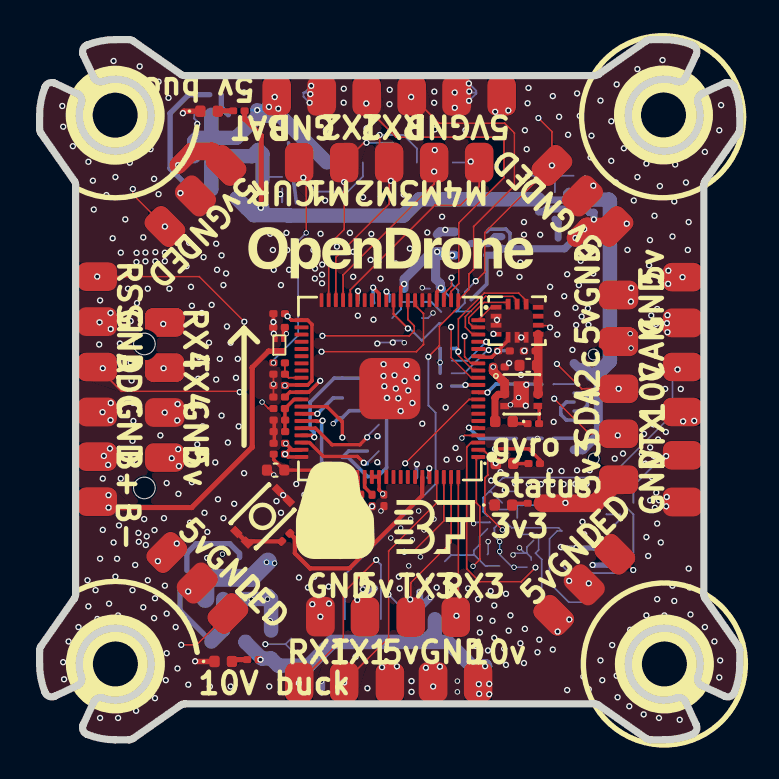
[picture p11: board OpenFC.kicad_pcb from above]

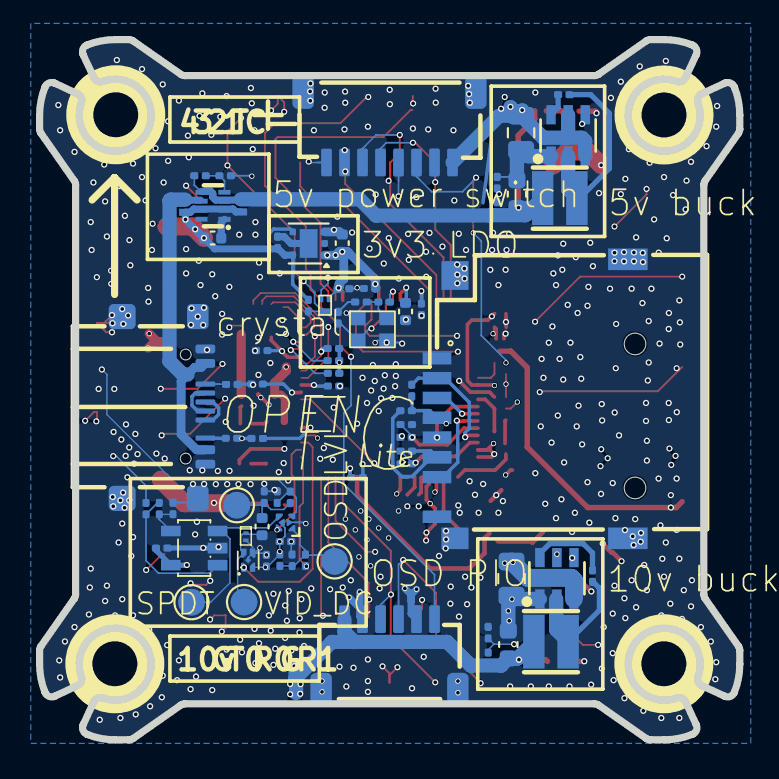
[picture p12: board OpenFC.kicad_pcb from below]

Board: 6 copper layers, 38.9 x 38.9 mm, 165 parts (74 on the bottom side), 84 nets.

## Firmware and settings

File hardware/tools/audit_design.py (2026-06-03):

#!/usr/bin/env python3
"""
OpenFC-Lite Design Audit.

Parses the KiCad 9 design using kicad-skip (schematics) and pcbnew (PCB netlist)
and produces a comprehensive hardware inventory + Betaflight MFG validation report.

Run with KiCad's bundled Python so pcbnew is available:
  /Applications/KiCad/KiCad.app/Contents/Frameworks/Python.framework/Versions/Current/bin/python3 \
    hardware/tools/audit_design.py
"""

from __future__ import annotations

import collections
import os
import re
import sys
from pathlib import Path

HW = Path(__file__).resolve().parents[1]
ROOT_SCH = HW / "OpenFC.kicad_sch"
PCB = HW / "OpenFC.kicad_pcb"
OUT = HW / "tools" / "design_audit.md"

# ---------- Parsers ----------

# kicad-skip: path setup for user-level install
sys.path.insert(0, "/Users/stan/Library/Python/3.13/lib/python/site-packages")
try:
    from skip import Schematic
except ImportError:
    print("ERROR: kicad-skip not available. pip install kicad-skip", file=sys.stderr)
    sys.exit(1)

try:
    import pcbnew  # type: ignore
except ImportError:
    print("ERROR: pcbnew not on path. Run with KiCad bundled Python.", file=sys.stderr)
    sys.exit(1)


# ---------- Schematic walk ----------

def list_sheets(root_sch: Path):
    """Return list of (sheetname, sheetfile) pairs referenced from root."""
    s = Schematic(str(root_sch))
    out = []
    for sh in s.sheet:
        props = {p.name: p.value for p in sh.property}
        out.append((props.get("Sheetname", "?"), props.get("Sheetfile", "?")))
    return out


def collect_symbols(sch_path: Path):
    """Parse a schematic; return list of dicts per placed symbol."""
    try:
        s = Schematic(str(sch_path))
    except Exception as e:
        print(f"  WARN: cannot parse {sch_path.name}: {e}", file=sys.stderr)
        return []
    out = []
    for sym in s.symbol:
        try:
            lib_id = sym.lib_id.value
        except Exception:
            continue
        props = {p.name: p.value for p in sym.property}
        ref = props.get("Reference", "?")
        if ref.startswith("#"):
            continue  # power flag / gnd
        # Filter out stray power-flag symbols mis-refed in sub-sheets (e.g. blackbox
        # sub-sheet has U1..U9 that are actually +3.3V / GND power symbols).
        lib_id_lower = lib_id.lower()
        if lib_id_lower.startswith("power:") or lib_id_lower == "power":
            continue
        out.append({
            "sheet": sch_path.stem,
            "ref": ref,
            "value": props.get("Value", ""),
            "footprint": props.get("Footprint", ""),
            "mpn": props.get("MPN", ""),
            "lcsc": props.get("LCSC_Part", "") or props.get("LCSC", ""),
            "mfr": props.get("Manufacturer", ""),
            "description": props.get("Description", ""),
            "lib_id": lib_id,
            "dnp": bool(getattr(sym, "dnp", None) and sym.dnp.value),
            "on_board": bool(getattr(sym, "on_board", None) and sym.on_board.value),
        })
    return out


# ---------- PCB walk ----------

def load_pcb(pcb_path: Path):
    return pcbnew.LoadBoard(str(pcb_path))


def footprint_index(board):
    """ref -> {pads: {pad_num: netname}, funcs: {pad_num: pinfunc}, ...}"""
    idx = {}
    for fp in board.GetFootprints():
        r = fp.GetReference()
        pads = {}
        funcs = {}
        for pad in fp.Pads():
            num = pad.GetNumber()
            pads[num] = pad.GetNetname() or ""
            try:
                funcs[num] = pad.GetPinFunction() or ""
            except Exception:
                funcs[num] = ""
        idx[r] = {
            "value": fp.GetValue(),
            "footprint": fp.GetFPID().GetLibItemName().c_str() if hasattr(fp.GetFPID(), "GetLibItemName") else "",
            "pads": pads,
            "funcs": funcs,
        }
    return idx


def net_to_refpins(board):
    """netname -> list of (ref, pad_num, pad_name/function)"""
    d = collections.defaultdict(list)
    for fp in board.GetFootprints():
        r = fp.GetReference()
        for pad in fp.Pads():
            name = pad.GetNetname() or ""
            d[name].append((r, pad.GetNumber(), pad.GetPinFunction() if hasattr(pad, "GetPinFunction") else ""))
    return d


# ---------- Classification ----------

FUNC_RULES = [
    ("MCU",       lambda s: s["ref"].startswith("U") and "RP235" in s["value"].upper()),
    ("IMU",       lambda s: "LSM6" in s["value"].upper() or "ICM-4" in s["value"].upper() or "MPU6" in s["value"].upper()),
    ("Buck",      lambda s: s["ref"].startswith("U") and "LMR5" in s["value"].upper()),
    ("LDO",       lambda s: s["ref"].startswith("U") and ("LP5912" in s["value"].upper() or "NCV8187" in s["value"].upper())),
    ("Power Mux", lambda s: "TPS2116" in s["value"].upper()),
    ("OSD",       lambda s: "TLV3201" in s["value"].upper() or "TLV9061" in s["value"].upper() or "LVC1G3157" in s["value"].upper() or "PI3A223" in s["value"].upper()),
    ("SD card",   lambda s: "TF-" in s["value"].upper() or "SD" == s["ref"][:2].upper() and "CARD" in s["description"].upper()),
    ("USB",       lambda s: s["ref"].startswith("USB") or "USB" in s["value"].upper() and s["ref"].startswith("J") or s["ref"] == "USB1"),
    ("Switch",    lambda s: s["ref"].startswith("SW") or "TS2306" in s["value"].upper()),
    ("Connector", lambda s: s["ref"].startswith("J") or "CONN" in s["lib_id"].upper()),
    ("Test Pad",  lambda s: s["ref"].startswith("TP")),
    ("MOSFET",    lambda s: s["ref"].startswith("Q")),
    ("Diode/LED", lambda s: s["ref"].startswith("D") and ("LED" in s["value"].upper() or "LED" in s["description"].upper())),
    ("Diode",     lambda s: s["ref"].startswith("D")),
    ("Inductor",  lambda s: s["ref"].startswith("L")),
    ("Ferrite",   lambda s: s["ref"].startswith("FB")),
    ("Resistor",  lambda s: s["ref"].startswith("R")),
    ("Capacitor", lambda s: s["ref"].startswith("C")),
    ("IC",        lambda s: s["ref"].startswith("U")),
]

def classify(sym):
    for name, fn in FUNC_RULES:
        try:
            if fn(sym):
                return name
        except Exception:
            continue
    return "Misc"


# ---------- Report builders ----------

def refs_on_net(net2rp, netname, exclude_refs=None):
    exclude_refs = set(exclude_refs or [])
    return [(r, n, f) for (r, n, f) in net2rp.get(netname, []) if r not in exclude_refs]


def find_caps_between(syms_by_ref, net2rp, netname_a, netname_b="GND"):
    """Return list of cap refs having one pad on netname_a and other on netname_b."""
    caps_on_a = {r for (r, _, _) in net2rp.get(netname_a, []) if r.startswith("C")}
    caps_on_b = {r for (r, _, _) in net2rp.get(netname_b, []) if r.startswith("C")}
    return sorted(caps_on_a & caps_on_b, key=lambda x: int(re.sub(r"\D", "", x) or 0))


def find_nets_matching(net2rp, *patterns):
    pats = [re.compile(p, re.I) for p in patterns]
    return [n for n in net2rp if any(p.search(n) for p in pats)]


def pad_net(fp_idx, ref, pad_num):
    return fp_idx.get(ref, {}).get("pads", {}).get(str(pad_num), "")


def md_table(headers, rows):
    out = ["| " + " | ".join(headers) + " |",
           "|" + "|".join(["---"] * len(headers)) + "|"]
    for row in rows:
        out.append("| " + " | ".join(str(x) for x in row) + " |")
    return "\n".join(out)


# ---------- Main audit ----------

def main():
    lines = []
    W = lines.append

    W("# OpenFC-Lite Design Audit\n")
    W(f"Generated from `{ROOT_SCH.name}` + `{PCB.name}` via kicad-skip + pcbnew.\n")

    # ---- 1. Hierarchy ----
    W("## 1. Top-level Hierarchy\n")
    sheets = list_sheets(ROOT_SCH)
    rows = []
    for name, path in sheets:
        exists = (HW / path).exists()
        rows.append([name, f"`{path}`", "yes" if exists else "**MISSING**"])
    W(md_table(["Sheetname", "File", "On disk"], rows))
    W("")
    W(f"Root schematic: `{ROOT_SCH.name}` — {len(sheets)} sub-sheet(s) referenced.\n")

    # ---- 2. Components ----
    W("## 2. Component Inventory\n")
    all_syms = []
    for name, path in sheets:
        p = HW / path
        if p.exists():
            all_syms.extend(collect_symbols(p))
    # Deduplicate by ref (symbols may appear in multiple places due to power/gnd)
    seen = {}
    for s in all_syms:
        seen.setdefault(s["ref"], s)
    syms = list(seen.values())

    W(f"Total placed refs: **{len(syms)}** (DNP excluded: "
      f"{len([s for s in syms if s['dnp']])}).\n")

    by_func = collections.defaultdict(list)
    for s in syms:
        by_func[classify(s)].append(s)

    # Print ICs, regulators, connectors etc fully; print caps/resistors summarized
    DETAIL_FUNCS = ["MCU", "IMU", "Buck", "LDO", "Power Mux", "OSD",
                    "SD card", "USB", "Switch", "MOSFET",
                    "Diode/LED", "Diode", "IC", "Inductor", "Ferrite"]
    def ref_sort_key(ref):
        m = re.match(r"([A-Za-z]+)(\d+)", ref)
        if m:
            return (m.group(1), int(m.group(2)))
        return (ref, 0)

    for fn in DETAIL_FUNCS:
        items = sorted(by_func.get(fn, []), key=lambda x: ref_sort_key(x["ref"]))
        if not items:
            continue
        W(f"### {fn} ({len(items)})\n")
        rows = []
        for s in items:
            mpn = s["mpn"] or s["value"]
            dnp = " DNP" if s["dnp"] else ""
            rows.append([s["ref"] + dnp, s["value"], mpn, s["lcsc"] or "-",
                         s["mfr"] or "-", s["footprint"].split(":")[-1] if s["footprint"] else "-",
                         s["sheet"]])
        W(md_table(["Ref", "Value", "MPN", "LCSC", "Mfr", "Footprint", "Sheet"], rows))
        W("")
    # Connector summary only (detail in section 14)
    conns = by_func.get("Connector", [])
    if conns:
        W(f"### Connector / Solder Pads ({len(conns)})\n")
        W("(full net list in section 14)\n")
        # group by footprint
        fp_count = collections.Counter((s["footprint"].split(":")[-1] or "-", s["sheet"]) for s in conns)
        rows = [[fp, sh, c] for (fp, sh), c in sorted(fp_count.items())]
        W(md_table(["Footprint", "Sheet", "Count"], rows))
        W("")

    # Passives summary
    W("### Passives summary\n")
    rows = []
    for fn in ("Resistor", "Capacitor", "Test Pad"):
        items = [s for s in by_func.get(fn, []) if not s["dnp"]]
        dnp = [s for s in by_func.get(fn, []) if s["dnp"]]
        rows.append([fn, len(items), len(dnp)])
    W(md_table(["Function", "Placed", "DNP"], rows))
    W("")

    # ---- Load PCB for net-level analysis ----
    board = load_pcb(PCB)
    fp_idx = footprint_index(board)
    net2rp = net_to_refpins(board)

    # ---- 3. Power tree ----
    W("## 3. Power Tree\n")
    W("```")
    W("+BATT -> U6 (LMR51420YFDDCR buck) -> +12V   [switchable via GPIO11 via Q?]")
    W("+BATT -> U7 (LMR51420YFDDCR buck) -> +5V_BUCK")
    W("+5V_BUCK -+")
    W("          +- U33 (TPS2116 mux) -> +5V")
    W("VBUS(USB)-+")
    W("+5V -> U13 (LP5912-3.3) -> +3.3V")
    W("+3.3V -> U36 (RP2354B VREG) -> +1.1V_CORE (DVDD)")
    W("+5V -> U21 (NCV8187 LDO) -> +1.8V_GYRO")
    W("```\n")

    regs = [
        ("U6",  "LMR51420YFDDCR", "12V buck"),
        ("U7",  "LMR51420YFDDCR", "5V buck"),
        ("U13", "LP5912-3.3DRVR", "3.3V LDO"),
        ("U21", "NCV8187AMT180TAG", "1.8V gyro LDO"),
        ("U33", "TPS2116DRLR", "5V power mux"),
    ]
    rows = []
    for ref, mpn, role in regs:
        fp = fp_idx.get(ref, {})
        pads = fp.get("pads", {})
        # summarise input / EN / output if we can infer by pin function from schematic
        # Just print key pads
        rows.append([ref, role, mpn, fp.get("footprint", "-"),
                     "; ".join(f"{k}→{v}" for k, v in sorted(pads.items(), key=lambda x: int(x[0]) if x[0].isdigit() else 99))])
    W(md_table(["Ref", "Role", "MPN", "Footprint", "Pad → Net"], rows))
    W("")

    # ---- 4. Bypass caps per rail ----
    W("## 4. Bypass caps per power rail\n")
    rails = ["+BATT", "+12V", "+5V_BUCK", "+5V", "VBUS", "+3.3V", "+1.8V_GYRO",
             "+1.1V", "+1.1V_CORE", "DVDD"]
    rows = []
    for rail in rails:
        # try exact, then with leading /
        candidates = [rail, "/" + rail, rail.lstrip("+"), "/" + rail.lstrip("+")]
        found_net = None
        for c in candidates:
            if c in net2rp:
                found_net = c
                break
        if not found_net:
            # try loose match
            loose = [n for n in net2rp if n.strip("/+").upper() == rail.strip("/+").upper()]
            if loose:
                found_net = loose[0]
        if not found_net:
            rows.append([rail, "— (net not found)", "-", "-"])
            continue
        caps = find_caps_between({}, net2rp, found_net, "GND")
        # count how many pins are on this net (fanout size)
        fanout = len(net2rp.get(found_net, []))
        rows.append([rail, found_net, len(caps), ", ".join(caps) if caps else "—"])
    W(md_table(["Rail", "Net", "# Caps to GND", "Cap refs"], rows))
    W("")
    # Also report ALL nets that look like rails
    rail_like = [n for n in net2rp if re.search(r"(^|/)(\+?\d+V|VBUS|VBAT|VDD|AVDD|DVDD|VREG)", n, re.I)]
    W("Rail-like nets present:\n")
    W(", ".join(f"`{n}`" for n in sorted(set(rail_like))))
    W("")

    # ---- 5. ADC inputs ----
    W("## 5. ADC Inputs\n")
    adc_nets = {
        "VBAT_SENSE": ["VBAT", "VBATT_SENSE", "VBAT_ADC", "BATT_ADC", "VBAT_SCALE", "BATTERY_ADC"],
        "CURR_SENSE": ["CURRENT", "I_SENSE", "CURR_ADC", "CURR_SENSE", "IMON", "CURRENT_ADC"],
        "RSSI":       ["RSSI", "RSSI_ADC"],
        "EXT":        ["EXT_ADC", "ADC_EXT", "EXT"],
    }
    # Try to find the MCU's actual ADC pins: GPIO40,41,45,47 per CLAUDE.md
    mcu_ref = "U36"
    mcu_fp = fp_idx.get(mcu_ref, {})
    # The ADC nets go to MCU pins — find them by following net back to U36
    rows = []
    for role, candidates in adc_nets.items():
        net = None
        for c in candidates:
            match = [n for n in net2rp if c.upper() in n.upper()]
            if match:
                net = sorted(match, key=len)[0]
                break
        if not net:
            rows.append([role, "— not found", "-", "-", "-"])
            continue
        # Find MCU pad carrying this net
        mcu_pad = "-"
        for p, n in mcu_fp.get("pads", {}).items():
            if n == net:
                mcu_pad = p
                break
        # Find resistors on the net
        res = [r for (r, _, _) in net2rp.get(net, []) if r.startswith("R")]
        caps = find_caps_between({}, net2rp, net, "GND")
        rows.append([role, net, mcu_pad,
                     ", ".join(sorted(set(res))) or "—",
                     ", ".join(caps) or "**NONE**"])
    W(md_table(["Role", "Net", "MCU pad", "Resistors on net", "Bypass caps to GND"], rows))
    W("")
    W("**Check**: A CURRENT-sense ADC input WITHOUT a bypass cap at the MCU pin is a "
      "Betaflight MFG-guideline violation (noise couples straight into ADC).\n")

    # ---- 6. SPI buses & CS pull-ups ----
    W("## 6. SPI Buses & CS pull-ups\n")
    spi_nets = {
        "SPI0 SCK":  [n for n in net2rp if re.search(r"SPI0?_?SCK|GYRO_?SCK|IMU_?SCK", n, re.I)],
        "SPI0 MOSI": [n for n in net2rp if re.search(r"SPI0?_?(MOSI|SDI|SDA)|GYRO_?MOSI|IMU_?MOSI", n, re.I)],
        "SPI0 MISO": [n for n in net2rp if re.search(r"SPI0?_?(MISO|SDO)|GYRO_?MISO|IMU_?MISO", n, re.I)],
        "IMU CS":    [n for n in net2rp if re.search(r"(IMU|GYRO).*CS|CS_?(IMU|GYRO)", n, re.I)],
        "SD CS":     [n for n in net2rp if re.search(r"SD.*CS|CS_?SD|BB_?CS", n, re.I)],
        "SD MOSI":   [n for n in net2rp if re.search(r"SD.*MOSI|SD.*DI|SD_?CMD", n, re.I)],
        "SD MISO":   [n for n in net2rp if re.search(r"SD.*MISO|SD.*DO|SD_?DAT0?", n, re.I)],
        "SD SCK":    [n for n in net2rp if re.search(r"SD.*SCK|SD.*CLK", n, re.I)],
    }
    rows = []
    for role, nets in spi_nets.items():
        if not nets:
            rows.append([role, "—", "-", "-"])
            continue
        net = nets[0]
        # list refs on that net
        refs = sorted(set(r for (r, _, _) in net2rp[net]))
        # resistors on net (pull-up candidates)
        rs = [r for r in refs if r.startswith("R")]
        rows.append([role, net, ", ".join(refs), ", ".join(rs) or "—"])
    W(md_table(["Signal", "Net", "Refs on net", "Resistors (pull-ups?)"], rows))
    W("")

    # Specific checks for CS pull-ups
    W("### CS pull-up check (to +3.3V)\n")
    cs_checks = []

    def find_cs_pad(ref):
        """Return (pad_num, netname) for the CS pin of a footprint, using pin function."""
        fp = fp_idx.get(ref, {})
        for p, func in fp.get("funcs", {}).items():
            if re.search(r"(^|_)CS(_|$)", func or "", re.I):
                return p, fp.get("pads", {}).get(p, "")
        return None, None

    # IMU CS -> U14 using pin function
    pad, net = find_cs_pad("U14")
    cs_checks.append((f"IMU_CS (U14 pad {pad})", net))
    # SD CS -> Card2 pad 2 (TF-021B-H265 pinout: pin2=CS/DAT3)
    for ref, fp in fp_idx.items():
        v = fp.get("value", "").upper()
        if "TF-" in v or "MICROSD" in v:
            # TF socket pad 2 = CS in SPI mode
            n = fp.get("pads", {}).get("2", "")
            cs_checks.append((f"SD_CS ({ref} pad 2)", n))
            break
    rows = []
    for role, net in cs_checks:
        if not net:
            rows.append([role, "—", "—", "—"])
            continue
        rs = [r for (r, _, _) in net2rp.get(net, []) if r.startswith("R")]
        # Does any of those R's touch +3.3V or +3V3?
        has_pullup = False
        pu_ref = "-"
        for rref in rs:
            rpads = fp_idx.get(rref, {}).get("pads", {})
            other_nets = set(rpads.values()) - {net}
            if any(re.search(r"3V3|3\.3V|VDDIO", x, re.I) for x in other_nets):
                has_pullup = True
                pu_ref = rref
                break
        rows.append([role, net, "YES" if has_pullup else "NO", pu_ref])
    W(md_table(["CS line", "Net", "Pull-up present?", "Pull-up ref"], rows))
    W("")

    # ---- 7. Status LEDs ----
    W("## 7. Status LEDs (non-WS2812)\n")
    leds = [s for s in syms if s["ref"].startswith("D") and
            ("LED" in s["value"].upper() or "LED" in (s["description"] or "").upper())]
    rows = []
    for led in sorted(leds, key=lambda x: x["ref"]):
        ref = led["ref"]
        fp = fp_idx.get(ref, {})
        pads = fp.get("pads", {})
        # LEDs usually have A/K or 1/2
        pin_nets = ", ".join(f"{k}→{v}" for k, v in pads.items())
        # Try to identify MCU pin driving it (non-rail end)
        drivers = [v for v in pads.values() if not re.search(r"\+?(\d+V|GND|VBUS|VBAT)", v, re.I)]
        rows.append([ref, led["value"], led["mpn"] or "-", pin_nets, ", ".join(drivers) or "—"])
    W(md_table(["Ref", "Value/Color", "MPN", "Pad nets", "Likely MCU-side net"], rows))
    W("")
    # Blue LED check
    blue = [l for l in leds if "BLUE" in l["value"].upper() or "BLU" in l["value"].upper()]
    W(f"Blue LED (Betaflight LED0 requirement): **{'PRESENT' if blue else 'MISSING'}** "
      f"({', '.join(l['ref'] for l in blue) or 'none'})\n")

    # ---- 8. I2C ----
    W("## 8. I2C Pull-ups\n")
    sda_net = [n for n in net2rp if re.search(r"I2C.*SDA|SDA$|/SDA", n, re.I)]
    scl_net = [n for n in net2rp if re.search(r"I2C.*SCL|SCL$|/SCL", n, re.I)]
    rows = []
    for role, nets in (("I2C_SDA", sda_net), ("I2C_SCL", scl_net)):
        if not nets:
            rows.append([role, "—", "-", "-"])
            continue
        net = nets[0]
        refs = sorted(set(r for (r, _, _) in net2rp[net]))
        rs = [r for r in refs if r.startswith("R")]
        has_pullup = False
        for rref in rs:
            rpads = fp_idx.get(rref, {}).get("pads", {})
            if any(re.search(r"3V3|3\.3V|VDDIO", x, re.I) for x in rpads.values()):
                has_pullup = True
                break
        rows.append([role, net, ", ".join(refs), "YES" if has_pullup else "**NO**"])
    W(md_table(["Signal", "Net", "Refs on net", "Pull-up to 3.3V"], rows))
    W("")

    # ---- 9. MCU pinout ----
    W("## 9. RP2354B (U36) Pinout\n")
    mcu_fp = fp_idx.get("U36", {})
    pads = mcu_fp.get("pads", {})
    rows = []
    for p in sorted(pads.keys(), key=lambda x: int(x) if x.isdigit() else 999):
        n = pads[p]
        # skip internal / power pads for clarity (keep but mark)
        rows.append([p, n])
    W(md_table(["Pad", "Net"], rows))
    W("")

    # ---- 10. OSD circuit ----
    W("## 10. OSD Circuit\n")
    osd_refs = [s["ref"] for s in syms if s["ref"] in ("U34", "U35", "U38")]
    rows = []
    for ref in osd_refs:
        fp = fp_idx.get(ref, {})
        rows.append([ref, fp.get("value"), fp.get("footprint"),
                     "; ".join(f"{k}→{v}" for k, v in fp.get("pads", {}).items())])
    W(md_table(["Ref", "Value", "Footprint", "Pad → Net"], rows))
    W("")

    # ---- 11. SD card ----
    W("## 11. SD Card (Blackbox)\n")
    sd_refs = [s for s in syms if
               "TF-" in s["value"].upper() or "MICROSD" in s["value"].upper() or
               "SD_CARD" in s["value"].upper() or "CARD" in s["description"].upper()]
    if not sd_refs:
        # look in pcb fps too
        for ref, fp in fp_idx.items():
            if "TF-" in fp.get("value", "").upper():
                sd_refs.append({"ref": ref, "value": fp["value"], "description": "", "lib_id": "",
                                "mpn": "", "lcsc": "", "footprint": fp.get("footprint", ""),
                                "mfr": "", "sheet": "", "dnp": False, "on_board": True})
    rows = []
    for s in sd_refs:
        ref = s["ref"]
        fp = fp_idx.get(ref, {})
        pads = fp.get("pads", {})
        rows.append([ref, s["value"], fp.get("footprint"),
                     "; ".join(f"{k}→{v}" for k, v in pads.items())])
    W(md_table(["Ref", "Value", "Footprint", "Pad → Net"], rows))
    W("")
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

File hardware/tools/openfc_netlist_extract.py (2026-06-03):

#!/usr/bin/env python3
from __future__ import annotations

import argparse
import csv
import json
import os
import re
from dataclasses import dataclass, asdict
from pathlib import Path
from typing import Any, Dict, Iterable, List, Optional, Tuple


Token = str


def tokenize_sexpr(text: str) -> List[Token]:
    tokens: List[Token] = []
    i = 0
    n = len(text)
    while i < n:
        ch = text[i]
        if ch.isspace():
            i += 1
            continue
        if ch in ("(", ")"):
            tokens.append(ch)
            i += 1
            continue
        if ch == '"':
            i += 1
            buf: List[str] = []
            while i < n:
                ch2 = text[i]
                if ch2 == "\\":
                    if i + 1 < n:
                        buf.append(text[i + 1])
                        i += 2
                        continue
                if ch2 == '"':
                    i += 1
                    break
                buf.append(ch2)
                i += 1
            tokens.append("".join(buf))
            continue
        # symbol
        j = i
        while j < n and (not text[j].isspace()) and text[j] not in ("(", ")"):
            j += 1
        tokens.append(text[i:j])
        i = j
    return tokens


class ParseError(RuntimeError):
    pass


def parse_sexpr(tokens: List[Token]) -> Any:
    i = 0

    def parse_one() -> Any:
        nonlocal i
        if i >= len(tokens):
            raise ParseError("unexpected end of tokens")
        tok = tokens[i]
        if tok == "(":
            i += 1
            lst: List[Any] = []
            while True:
                if i >= len(tokens):
                    raise ParseError("unterminated list")
                if tokens[i] == ")":
                    i += 1
                    return lst
                lst.append(parse_one())
        if tok == ")":
            raise ParseError("unexpected ')'")
        i += 1
        return tok

    expr = parse_one()
    if i != len(tokens):
        raise ParseError(f"trailing tokens at {i}/{len(tokens)}")
    return expr


def _kv(node: Any) -> Optional[Tuple[str, str]]:
    if isinstance(node, list) and len(node) == 2 and isinstance(node[0], str) and isinstance(node[1], str):
        return node[0], node[1]
    return None


def _find_sections(root: Any) -> Dict[str, Any]:
    sections: Dict[str, Any] = {}
    if not isinstance(root, list) or not root or root[0] != "export":
        raise ParseError("expected (export ...)")
    for item in root[1:]:
        if isinstance(item, list) and item:
            key = item[0]
            if isinstance(key, str) and key not in sections:
                sections[key] = item
    return sections


@dataclass
class Component:
    ref: str
    value: str = ""
    footprint: str = ""
    datasheet: str = ""
    description: str = ""
    sheetname: str = ""
    sheetfile: str = ""
    properties: Dict[str, str] = None  # type: ignore[assignment]
    fields: Dict[str, str] = None  # type: ignore[assignment]
    lib: str = ""
    part: str = ""
    connections: Dict[str, str] = None  # type: ignore[assignment]
    pinfunctions: Dict[str, str] = None  # type: ignore[assignment]

    def __post_init__(self) -> None:
        if self.properties is None:
            self.properties = {}
        if self.fields is None:
            self.fields = {}
        if self.connections is None:
            self.connections = {}
        if self.pinfunctions is None:
            self.pinfunctions = {}


def parse_components(components_section: Any) -> Dict[str, Component]:
    comps: Dict[str, Component] = {}
    for item in components_section[1:]:
        if not (isinstance(item, list) and item and item[0] == "comp"):
            continue
        ref = ""
        comp = Component(ref="")
        for sub in item[1:]:
            kv = _kv(sub)
            if kv:
                k, v = kv
                if k == "ref":
                    ref = v
                    comp.ref = v
                elif k == "value":
                    comp.value = v
                elif k == "footprint":
                    comp.footprint = v
                elif k == "datasheet":
                    comp.datasheet = v
                elif k == "description":
                    comp.description = v
                continue
            if isinstance(sub, list) and sub:
                if sub[0] == "fields":
                    for fld in sub[1:]:
                        if isinstance(fld, list) and fld and fld[0] == "field":
                            name = ""
                            text = ""
                            for fsub in fld[1:]:
                                kv2 = _kv(fsub)
                                if kv2 and kv2[0] == "name":
                                    name = kv2[1]
                                elif isinstance(fsub, str):
                                    text = fsub
                            if name:
                                comp.fields[name] = text
                elif sub[0] == "property":
                    name = ""
                    val = ""
                    for psub in sub[1:]:
                        kv2 = _kv(psub)
                        if kv2:
                            if kv2[0] == "name":
                                name = kv2[1]
                            elif kv2[0] == "value":
                                val = kv2[1]
                    if name:
                        comp.properties[name] = val
                        if name == "Sheetname":
                            comp.sheetname = val
                        if name == "Sheetfile":
                            comp.sheetfile = val
                elif sub[0] == "libsource":
                    for lsub in sub[1:]:
                        kv2 = _kv(lsub)
                        if kv2:
                            if kv2[0] == "lib":
                                comp.lib = kv2[1]
                            elif kv2[0] == "part":
                                comp.part = kv2[1]
        if ref:
            comps[ref] = comp
    return comps
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

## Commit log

2026-06-03 Initial commit: OpenFC-Lite (standard 30.5×30.5 mm)
    Forked from OpenFC-Lite-Mini. Shares the RP2354B schematic; standard
    30.5×30.5 mm form factor. Docs/photos/production files still carry
    Mini artifacts and will be updated for the Lite board.
    [OpenFC.kicad_pcb, OpenFC.kicad_sch, blackbox.kicad_sch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]
2026-06-03 move changes from mini over to "maxi"
    [blackbox.kicad_sch, imu.kicad_sch, leds.kicad_sch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]
2026-06-04 rev2 update
    [OpenFC.kicad_pcb, blackbox.kicad_sch, osd.kicad_sch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]
2026-06-04 lite done
    [blackbox.kicad_sch, rp2350a.kicad_sch]
2026-06-06 reinsert resistor that kicad randomly deleted
    [OpenFC.kicad_pcb]
2026-06-06 BF connector standard logo
    https://betaflight.com/docs/development/manufacturer/connector-standard
    [OpenFC.kicad_pcb]
2026-06-06 Rev 2: finalize schematic + PCB for fabrication
    Rev 2 change list implemented; on-canvas design annotations added across all
    sheets (root, rp2350a, power, imu, osd, blackbox, pads). Design frozen for ordering.
    [OpenFC.kicad_pcb, OpenFC.kicad_sch, blackbox.kicad_sch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]
2026-06-06 docs: rebrand as full-size OpenFC-Lite; add DESIGN_NOTES
    - README: identify as full-size 30.5mm Lite (RP2354B); link Mini + Wiki;
    drop schematic-provenance scaffolding; point bring-up/testing to the Wiki
    - CLAUDE.md: fix stale "Mini" identity; mark Rev 2 as current (implemented/ordered)
    - add hardware/DESIGN_NOTES.md: schematic design rationale (SSoT mirror)
    - gitignore: also ignore board-level *.step exports under hardware/
2026-06-06 feat(doc): add DOC_ project text variables
    Project-level documentation SSoT in .kicad_pro: DOC_NAME/HANDLE/VARIANT/TAGLINE/FIRMWARE/PROTOCOL/MCU/INPUT/RATING.
2026-06-06 chore: untrack CLAUDE.md — local-only agent context, never on git
2026-06-06 docs: gyro LDO is NCV8187 1.2A high-PSRR (fix vs design + datasheet)
    Was mislabelled 300mA; the 1.2A rating clears BF §3.1.2's ≥500mA. Reconciled against the on-canvas KiCad comment.
2026-06-06 chore(bom): consolidate LCSC Part -> LCSC field across schematic, library, footprints, project
    Single canonical LCSC field (was split LCSC / LCSC Part). Every part resolves to one LCSC code; netlist verified, no duplicates. Includes Rev2 re-annotation resync re-save.
    [OpenFC.kicad_pcb, blackbox.kicad_sch, imu.kicad_sch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]
2026-06-06 docs: Rev 2 board renders (standardized top/bottom)
    kicad-cli 3D renders, 1600x1600 high-quality, transparent bg, ortho top/bottom. Replaces Rev 1 images.
2026-06-06 docs: note both boards ship for Rev 2; OSD debug pads on full-size
2026-06-07 docs: via-free board renders
    Re-render top/bottom board images with vias removed for a cleaner look.
    KiCad cannot render tented vias, so vias were temporarily stripped via the
    pcbnew API for rendering only; source .kicad_pcb files are unchanged.
2026-06-07 docs: re-render boards without floor shadows
    Re-render top/bottom images at basic quality so the soldermask floor
    shadow halo is gone. Vias still stripped for the render only (via pcbnew),
    source .kicad_pcb files unchanged.
2026-06-07 docs: render boards without solder paste
    Strip the solder-paste layer (and vias) for the render only so SMD pads
    show as clean copper instead of gray paste deposits. Source .kicad_pcb
    files unchanged.
2026-06-07 docs: remove DESIGN_NOTES, trim README boilerplate
    - Delete DESIGN_NOTES.md (and its gitignore exception)
    - Drop the Manufacturing / production-export section
    - Remove the canonical-reference boilerplate blurb
    - ESC boards: AM32 bootloader ships pre-loaded, firmware flashed via am32.ca
